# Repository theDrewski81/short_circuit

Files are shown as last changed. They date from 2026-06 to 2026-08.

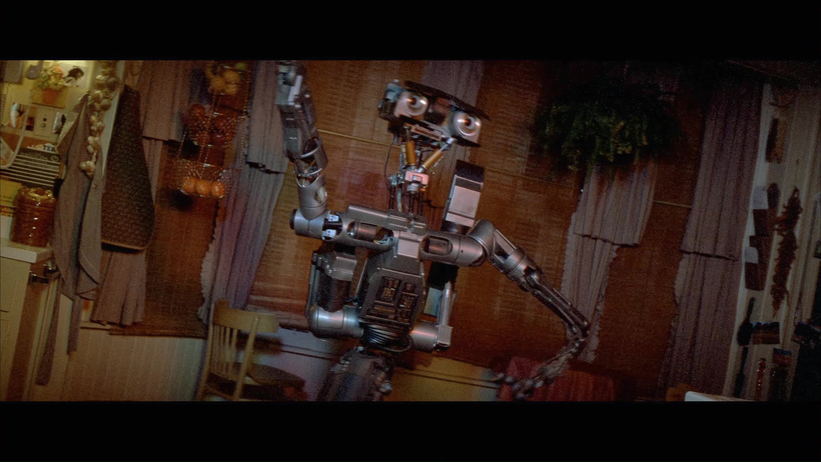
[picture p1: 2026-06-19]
reference_images/f872ac491efb3785fa1dbe327b1345db-o.jpg

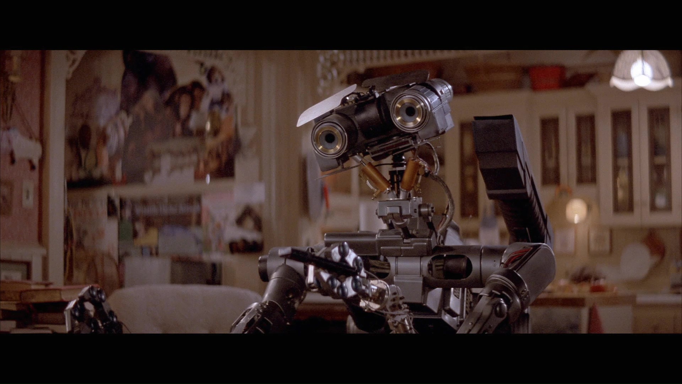
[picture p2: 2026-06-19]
reference_images/b916a9b340c59056be2ff8090a524d04-o.jpg

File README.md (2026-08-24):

# Johnny 5

A playful, Johnny 5-inspired (*Short Circuit*, 1986) autonomous robot. Tread-driven
locomotion, two articulated arms, a rotating head, voice I/O, and visual perception.
An LLM handles reasoning and communication; ML-trained motor policies handle motion
control.

Full project brief: [`CLAUDE.md`](./CLAUDE.md).

## Architecture

Two Raspberry Pi Zero 2 W units with distinct roles, communicating over MQTT via a
Mosquitto broker on the home lab.

- **Pi-M (Motion)** — fixed-rate motor control loop, tread drive, arm/head servos,
  ToF + IMU sensing, LED status ring. Never blocks on the network.
- **Pi-V (Vision)** — camera capture, voice input, and the LLM agent loop. Calls out
  to a home lab LiteLLM proxy and pushes intent updates to Pi-M.

LLM inference runs on existing home lab infrastructure (RTX 3080 / Proxmox cluster)
via LiteLLM — no dedicated serving layer for this project. Motion policies are
trained in MuJoCo on the home lab and deployed to Pi-M as ONNX.

See `src/shared/PROTOCOL.md` for the Pi-M ↔ Pi-V message contract.

## Repository Layout

```
mechanical/   FreeCAD source + STL exports
phases/       Per-phase coordinator documents
src/          motion/ (Pi-M), vision/ (Pi-V), shared/ (message contracts)
simulation/   MuJoCo models and training code
policies/     Trained policy exports (ONNX)
scripts/      Setup, deployment, and maintenance scripts
```

## Status

Current phase, blockers and next steps live in [`PROJECT_STATE.md`](./PROJECT_STATE.md),
which is the project's single source of truth for where the work stands.

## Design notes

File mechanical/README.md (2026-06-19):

# Johnny 5 — Mechanical (FreeCAD, parametric)

All body geometry is generated from a single parameter sheet by headless Python
build scripts. Nothing is modelled by hand in the GUI.

```
mechanical/
  freecad/
    params.csv            single source of truth (locked + design dims)
    j5_params.py          CSV loader + derived geometry (no FreeCAD dependency)
    j5_lib.py             Part-scripting helpers (boxes, bosses, keyed splits, export)
    build_chassis.py      chassis / tread base build  → STL + FCStd
    chassis_assembly_v1.FCStd   (generated)
  stl/                    generated STL exports for printing
  preview/
    validate.py           FreeCAD-free param checks (bed fit, clearance, packaging, mass)
    preview_chassis.py    matplotlib massing preview → PNG
    chassis_massing_v1.png
```

## Generate the chassis

```
cd mechanical/freecad
freecadcmd build_chassis.py          # FreeCAD 1.1.1; writes STLs to ../stl and the FCStd here
```

(or paste `build_chassis.py` into the FreeCAD Python console)

## Check before printing

```
cd mechanical/preview
python3 validate.py                  # all-PASS gate on the parameters
python3 preview_chassis.py           # regenerate the massing preview
```

## Conventions

World origin at the centre of the track footprint, on the ground plane.
**+X right, +Y forward, +Z up.** Edit `params.csv` and re-run — never edit
dimensions inside the scripts. `locked=1` rows trace to the approved BOM and the
Phase 00 handoff; changing one is a phase decision.

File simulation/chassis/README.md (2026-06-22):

# Johnny 5 — Tread Chassis Simulation (Phase 02)

Chassis-only MuJoCo environment for training the locomotion policy. Arms and
head are out of scope here (added in Phase 03); their mass rides on the chassis
as a lumped trunk inertia.

## Files

| File | Role |
|---|---|
| `params.py` | SI-unit parameter bridge. Reads `mechanical/freecad/params.csv` (CAD source of truth) and declares the non-CAD modelling constants (motor torque, friction, mass split, CoM height) with their basis. |
| `build_mjcf.py` | Generates `johnny5_chassis.xml` from `params.py`. Re-run after any params change. |
| `johnny5_chassis.xml` | Generated MJCF. **Do not hand-edit** — change `params.py`/`params.csv` and regenerate. |
| `env.py` | Gymnasium environment `JohnnyChassisEnv` (command-conditioned). |
| `test_env.py` | Pre-training stability + sanity checks (random + scripted rollouts). |
| `TUNING.md` | Sim-vs-reality assumptions to confirm on the bench (Phase 02 Task 6). |

Regenerate the model:

```bash
python3 simulation/chassis/build_mjcf.py
```

## Modelling assumptions

**Treads → four driven wheels.** Each tread is two cylinders (front + rear,
spanning the 120 mm wheelbase) rather than a deformable belt. Deformable track
contact is expensive and numerically fragile, and the policy only needs the
left/right-speed → body-motion mapping. A *single* wheel per side collapses the
fore-aft contact patch to a point, and the tall robot nose-dives; front + rear
wheels restore the support polygon. The real belt couples the front idler to the
rear sprocket, so both turn at track speed — hence all four wheels are driven, in
left/right pairs (the env writes one command to each side's two wheels).

**DC motor → torque actuator + damping droop.** Each wheel is a torque source
(`gear` = stall torque / 2) with joint damping `b = stall / (2·no_load)`. The
factor of two splits one physical motor's torque-speed line across its two
wheels, so the per-side behaviour matches one brushed motor: full command settles
the side near its no-load speed (~0.30 m/s) instead of accelerating without
bound. Stall 0.25 N·m and no-load 12.9 rad/s are datasheet figures scaled from
12 V to the 7.4 V battery-direct rail — **confirm on the bench** (TUNING.md).

**Skid-steer turn resistance is real, not a bug.** Contacts use `condim=3`
(slide friction only). Turning comes from lateral skid of four wheels spread over
the wheelbase, so in-place yaw is resistance-limited. Measured envelope on the
default floor: forward cap ~0.30 m/s, in-place yaw cap ~0.34 rad/s. The env
command ranges (`V_MAX=0.28`, `W_MAX=0.30`) sit just inside these.

**Rear caster → rigid low-friction sphere.** The physical part is a sprung,
swivelling trailing caster; for locomotion it is a rigid low-friction support
sphere placed half the nominal trail behind the rear track edge, giving the same
rearward tip support without joint-tuning fragility.

**Trunk inertia → solid-box proxy.** Mass 1.197 kg at CoM height 0.110 m, with a
box inertia using the tub footprint and an effective height of 0.18 m to account
for the torso/head/arm mass riding above the (collision-only) tub.

## Environment

`JohnnyChassisEnv` — command-conditioned, one policy for all behaviours.

- **Control rate:** 50 Hz (matches the Pi-M motion-loop tick); 10 physics
  substeps per control step at 500 Hz.
- **Action:** `[left, right]` motor effort in `[-1, 1]`, each applied to that
  side's two wheels.
- **Observation (9):** body-frame forward/lateral velocity, yaw rate, roll,
  pitch, left/right encoder velocity, and the command `[v_cmd, w_cmd]`.
- **Command modes:** forward, backward, spin-left, spin-right, arc, stop —
  sampled per episode to cover the four Phase 02 behaviours plus hold.
- **Reward:** `w_vel·exp(-k·(v−v_cmd)²) + w_yaw·exp(-k·(ψ̇−w_cmd)²)
  − energy − stability(roll²+pitch²) − lateral-skid`. Tip-over
  (|roll| or |pitch| > 0.8 rad) terminates with a penalty. Weights are
  constructor kwargs, set from `config.yaml` in training (Task 4).

## Pre-training check

```bash
python3 simulation/chassis/test_env.py
```

Confirms physics stability (no NaN/inf, no spurious tip-overs under random
actions) and that a scripted differential controller out-scores random control —
i.e. the reward is trackable — before committing GPU time to training.

## Training (Task 4)

PPO via Stable-Baselines3, command-conditioned, small MLP (`net_arch: [64, 64]`)
for fast onnxruntime inference on Pi-M. Hyperparameters and reward weights live in
`config.yaml`.

```bash
# full run on the RTX 3080 workstation node (see "Where to run" below)
python3 simulation/chassis/train.py --config config.yaml --n-envs <physical_cores> --device cpu
# -> runs/locomotion_v1/{model.zip, best/, vecnormalize.pkl, tb/}

# export the trained policy for the Pi (raw obs -> action, obs-norm baked in)
python3 simulation/chassis/export_onnx.py --run locomotion_v1
# -> policies/locomotion_v1.onnx
```

`train.py` trains all four Phase 02 behaviours (forward / backward / turn-in-place /
arc) plus stop from a single command-conditioned policy, uses `VecNormalize` for
observation/return normalisation, and saves the normalisation stats so they can be
folded into the ONNX graph at export. Watch progress with
`tensorboard --logdir runs/`.

### Where to run on the home lab

Run the single training job on the **RTX 3080 workstation node** (128 GB RAM),
not the Proxmox cluster. Rationale: throughput here is bound by MuJoCo env
stepping on the CPU, and the policy is a tiny 2x64 MLP whose gradient update is
trivial — a GPU adds little and the CPU<->GPU round-trip can even slow a net this
small. So use `--device cpu` with `--n-envs` set to the box's physical core count
(`SubprocVecEnv` parallelises the rollout across cores); the RTX 3080 is incidental
here, chosen for its cores and RAM, not its CUDA. 3M steps lands in roughly tens of
minutes at ~5k env-steps/s/core.

Bare metal or a single VM/LXC with the cores pinned both work — no GPU passthrough
needed. Reserve the Proxmox cluster for *parallel* hyperparameter sweeps (one run
per VM/LXC via `--run-name`), which is the async-batch case, not a single faster run.

### Sandbox note — why training runs on the home lab, not here

PyTorch/SB3 cannot be installed in the Cowork sandbox: the network proxy blocks
the PyTorch CPU wheel index and stalls the large CUDA wheels. So the SB3 PPO run
is a home-lab step. To still de-risk the pipeline before spending home-lab time,
`cem_smoke.py` is a torch-free check (numpy CEM + onnx/onnxruntime only):

```bash
python3 simulation/chassis/cem_smoke.py
```

It trains a small MLP on the env with the cross-entropy method and confirms (a)
the reward is learnable — trained policy beats random init by a wide margin — and
(b) the ONNX deployment path (raw obs → [-1,1] action, normalisation baked in)
reproduces the numpy forward on onnxruntime with sub-millisecond latency. Outputs
land in `smoke_run/` (a representative 1×16 net, distinct from the production 2×64).
These are throwaway validation artifacts, not the deployed policy.

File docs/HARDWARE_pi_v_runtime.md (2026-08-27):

# Pi-V Runtime Environment – the box, the camera, the dependency file, and the audio gap

What is known about Pi-V, the vision unit, and where each fact comes from. Pairs with
`docs/HARDWARE_pi_m_runtime.md`, which does the same for the motion unit, and with
`docs/HARDWARE_power_harness.md`, which covers Pi-V's wiring rather than its software.

**This document is weaker evidence than its Pi-M counterpart, and the difference matters.**
Every fact in `docs/HARDWARE_pi_m_runtime.md` was learned at the Task 1 bench bringup on
2026-07-12, on the hardware. Nothing here was. Pi-V has had no equivalent bringup session
and no agent session can reach `192.168.1.218`, so every claim below is traced to the
repository file that states it, and everything the repository does not state is marked as
not stated rather than filled in. Where this document and the Pi disagree, the Pi wins and
this document is wrong.

## The box

| | | Source |
|---|---|---|
| Host | `johnny5-vision`, `192.168.1.218` (static) | `phases/PHASE_01_INFRASTRUCTURE.md` task 2; `PROJECT_STATE.md` section 9, 2026-06-20; `scripts/_common.sh` |
| OS | Raspberry Pi OS Lite 64-bit, Trixie | `PROJECT_STATE.md` section 9, 2026-06-20 ("Both Pis on Raspberry Pi OS Lite 64-bit (Trixie)") |
| Login user | `administrator` | same entry; `scripts/_common.sh` default |
| System Python | **Not recorded for Pi-V.** See below. | — |
| venv | `~/johnny5-env` | `phases/PHASE_01_INFRASTRUCTURE.md` task 2 |
| Repo checkout | `~/johnny5` | `phases/PHASE_01_INFRASTRUCTURE.md` task 2; `scripts/_common.sh` `JOHNNY5_REMOTE_PATH` |
| LiteLLM virtual key alias | `johnny5-vision` on the AOS proxy | `PROJECT_STATE.md` section 9, 2026-06-22 |

**The system Python version is an inference, not a record.** `docs/HARDWARE_pi_m_runtime.md`
records Python 3.13 on Pi-M, and `PROJECT_STATE.md` puts both Pis on the same Trixie 64-bit
image, so 3.13 is what should be expected on Pi-V. No repository file states it, and nobody
has checked. Treat it as expected, not known. It is not academic: the Trixie plus Python 3.13
combination is exactly what makes `pip install lgpio` impossible on Pi-M, and any Pi-V package
with the same wheel problem would fail the same way.

**The static IP is NetworkManager-managed and could revert.** It was set with `nmcli` inside
the router's reservation block because dhcpcd is inactive on this OS version, and the profiles
are netplan-managed, so a future `netplan apply` could regenerate them. Recorded at S05 on
2026-06-20 and repeated here because the failure looks like a dead Pi rather than a
configuration change.

## Nothing provisions Pi-V

`scripts/setup_motion_pi.sh` provisions Pi-M: apt packages, I2C, the `pwm-2chan` overlay, the
udev rule, the venv with `--system-site-packages`, `pip install -r`, and a verification block
that prints the resolved path of each GPIO-side import. **There is no `setup_vision_pi.sh`, and
no other script provisions Pi-V.** The gap is real and is not a naming difference.

What does exist for Pi-V is deployment and access, which is a different job:

- `scripts/deploy_vision.sh` rsyncs `src/vision/` and `src/shared/` to the Pi and then runs
  `sudo systemctl restart johnny5-vision`. Its own comment says the service name and management
  are TBD and that the restart assumes a unit that may not exist; the restart is tolerated with
  `|| echo` rather than being fatal. **No systemd unit file for `johnny5-vision` exists in the
  repository.** `scripts/deploy_motion.sh` carries the identical caveat for `johnny5-motion`, so
  the TBD service is symmetric and is not part of the provisioning asymmetry.
- `scripts/ssh_vision.sh` is an SSH wrapper over the same `_common.sh` defaults.
- `scripts/check_health.sh` queries `johnny5/heartbeat/vision` on the broker at
  `MQTT_BROKER_HOST` and reports liveness. It runs from the development machine, not the Pi.

The provisioning steps that were actually performed on Pi-V exist only as prose in
`phases/PHASE_01_INFRASTRUCTURE.md` task 2: `apt install python3-pip python3-venv git
i2c-tools`, `raspi-config` for the camera, `python3 -m venv ~/johnny5-env`, and a clone into
`~/johnny5`. They were run by hand at S05 on 2026-06-20 and have never been captured in a
script, so re-provisioning or replacing Pi-V today means re-reading that task list and
repeating it manually. Whether that gap is worth closing with a `setup_vision_pi.sh` is an open
question raised by this document, not a decision it takes.

## The camera

The camera is the 8 MP 1080p CSI module on the head, one of two owned, connected by ribbon
rather than by GPIO (`BOM.md` section 7 and its Pi-V GPIO map).

Enablement, verbatim from `phases/PHASE_01_INFRASTRUCTURE.md` task 2: enable the camera
interface via `raspi-config`, then confirm the camera is detected with `libcamera-hello`. That
is the whole of the recorded enablement step, and there is no record in the repository of it
having been run or of what it printed.

**Two capture interfaces appear in the repository and they are not the same one.**
`scripts/whats_this_color.py`, the only program here that actually captures a frame, shells out
to `rpicam-still -o <path> --immediate -t 1000 -n`. `phases/PHASE_04_COGNITION.md` task 2
specifies `picamera2` for the real capture pipeline, explicitly rejects the legacy `picamera`
library, and warns that `picamera2` APIs differ between OS versions. That phase document names
Bookworm while this box runs Trixie, so its version caution applies to itself: the
`picamera2` version present on a Trixie image has not been confirmed against what Phase 04
assumes. Neither `picamera2` nor `rpicam-apps` is declared in any requirements file; both are
OS-supplied on Raspberry Pi OS images, and neither presence has been checked here.

## Dependencies are declared in `src/vision/requirements-vision.txt`

That file is the single dependency declaration for Pi-V, created by S18 against O8 and sited
beside the code it serves on the `simulation/chassis/requirements-train.txt` precedent. It
pins `httpx==0.28.1` and `python-dotenv==1.2.3` exactly rather than by range, and its header
explains why: a two-package runtime on a Pi Zero 2 W is not worth a silent minor bump in the
HTTP client.

```
pip install -r src/vision/requirements-vision.txt
```

It covers `src/vision/llm_client.py` plus the two Pi-V bench scripts that drive it,
`scripts/test_llm_client.py` and `scripts/whats_this_color.py`; everything else those three
modules import is standard library. `llm_client.py` imports `httpx` only, and `python-dotenv`
is imported by the two scripts. **The pins are current PyPI releases as of 2026-08-25 and have
not been verified against Pi-V**; the file says so itself, and if a `pip install -r` on the Pi
disagrees with a working install, the Pi wins and the file is corrected to match it.

What the file does not cover is everything Phase 04 adds. The camera library, the VAD model,
the transcription client, the TTS path, the MQTT client and the WS2812B driver for the mouth
array are all named in `phases/PHASE_04_COGNITION.md` and declared nowhere. That is expected
for unwritten code and is noted so the file is not mistaken for a complete Pi-V runtime.

## Configuration comes from `.env`

`.env` is gitignored on both Pis; `.env.example` at the repository root is the committed
template and carries the confirmed values and their rationale. The Pi-V half of it is the
LiteLLM client block and the shared MQTT block.

`LITELLM_ENDPOINT` is the existing Agentic OS proxy at `http://192.168.1.223:4000/v1`, reused
rather than rebuilt. `LITELLM_MODEL` is `vision-batch`, which routes to `llava:7b` on the
CPU-only Ollama node ms3 at `192.168.1.225`, chosen so vision inference does not contend with
desktop GPU work. `LITELLM_TIMEOUT` is **60.0**, not the 8.0 that `LiteLLMConfig` defaults to
in code: llava on a CPU node takes 15 to 40 seconds per image and longer on a cold load, and
the 8.0 s placeholder from the Phase 01 task list would have abandoned every call before the
model answered. `LiteLLMConfig.from_env()` raises on a missing endpoint, key or model rather
than falling back to a default, on the reasoning that a wrong endpoint is worse than a loud
failure.

The MQTT block points at the Mosquitto LXC `sn-mosquitto` at `192.168.1.227:1883`, confirmed
live 2026-06-20.

## Audio does not work yet, and the overlay that would fix it is unwritten

All audio is on Pi-V: the INMP441 I²S MEMS microphone and the MAX98357A I²S class-D amplifier
share one I²S bus, consolidated here at S01 on 2026-06-17 specifically to free Pi-M's I²S. On
the Pi-V header that is BCLK on GPIO18, LRCLK on GPIO19, mic data in on GPIO20 and amplifier
data out on GPIO21 (`BOM.md` Pi-V GPIO map, and the `SIG_I2S_*` nets in
`docs/HARDWARE_power_harness.md`).

**Two codecs on one bus need a device-tree overlay that has never been written.** The stock
`max98357a` and `googlevoicehat` overlays conflict; what is required is a custom combined
`simple-audio-card` overlay with one CPU DAI and two codec DAIs. This is **O1** in
`PROJECT_STATE.md` section 7, open since 2026-06-17, owned by a worker session and due in
Phase 04. It is referenced in `BOM.md`, in `phases/PHASE_00_HARDWARE.md`, and on the power
harness schematic, and until now it has been recorded only in prose with no home.

**This file is that home.** When the overlay is written, it belongs in this document, in the
form Pi-M's `pwm-2chan` section takes: the exact `/boot/firmware/config.txt` line, why each
argument is load-bearing, what the failure looks like without it, and the one command that
proves it loaded after a reboot. **It is deliberately not attempted here.** Writing a
device-tree overlay for two codecs that no session can test on the hardware they run on would
be a gate met against an unbuilt artifact, which this project has already done once and
recorded the lesson for. It stays Phase 04 work, to be done with the mic and amplifier wired
and a Pi in front of whoever is doing it. Half-duplex turn-taking with the mic gated during
playback is the intended behaviour, also Phase 04; there is no acoustic echo cancellation in
V1.

## Hardware PWM on Pi-V is unrecorded

`BOM.md` assigns the 1 W navigation light to Pi-V GPIO13 as a hardware PWM output driving a
MOSFET gate, and `docs/HARDWARE_power_harness.md` carries the same on `SIG_NAV_PWM`. Pi-M
needed an explicit `dtoverlay=pwm-2chan,pin=12,func=4,pin2=13,func2=4` line and a reboot before
`/sys/class/pwm` was populated at all. **No equivalent line is recorded anywhere for Pi-V**,
and whether one is needed there, and whether it can coexist with the I²S assignment on the same
header, is not answered by any file in this repository. Flagged rather than guessed; it belongs
with the O1 audio work, since both are `config.txt` questions on the same box.

## The Pi-V header, for reference

From `BOM.md`'s Pi-V GPIO pin map. 40-pin header, 3.3 V logic.

| Function | GPIO (BCM) | Notes |
|---|---|---|
| CSI camera | (ribbon) | Not GPIO |
| I²S BCLK / LRCLK | 18 / 19 | PCM clock / frame-sync, shared by mic and amplifier |
| I²S DIN (mic SD) | 20 | INMP441 into the Pi |
| I²S DOUT (amp DIN) | 21 | Pi into the MAX98357A |
| WS2812B mouth array | 10 | SPI0 MOSI, via a 74AHCT125 level shifter |
| Navigation light | 13 | Hardware PWM to a MOSFET gate |

Inter-Pi messaging runs over the WiFi LAN via the broker; no GPIO cross-link is reserved.

## What in this document is unverified

Stated once, in one place, so it cannot be missed:

- **Everything about the running state of Pi-V.** No agent session can reach `192.168.1.218`,
  and Pi-V has had no bench bringup session of the kind that produced the Pi-M document. The
  host, OS, user, venv path and checkout path are all as configured at S05 on 2026-06-20 and
  as the deployment scripts assume, not as observed since.
- **The system Python version**, which no file records for Pi-V.
- **The camera enablement step**, which is a documented instruction with no record of its
  having been run or of `libcamera-hello` succeeding.
- **The dependency pins**, which are PyPI releases as of 2026-08-25 and have never met the Pi.
- **The presence of `picamera2` or `rpicam-apps`**, and their versions on a Trixie image.

The way to close all of these at once is a Pi-V bringup session with the box in hand, the way
2026-07-12 closed them for Pi-M. Until then this document records what the repository knows,
which is not the same as what is true.

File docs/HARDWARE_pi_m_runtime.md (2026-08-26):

# Pi-M Runtime Environment — venv, GPIO packages, hardware PWM

What `scripts/setup_motion_pi.sh` provisions on Pi-M and, more usefully, the three
things about that box which are not obvious from reading the script. Pairs with
`docs/HARDWARE_drive_bringup.md`, which covers the wiring rather than the software.

Every fact here was learned at the Task 1 bench bringup on 2026-07-12 and lived
until 2026-08-25 only in a loose project-memory note at the repository root, which
is why `setup_motion_pi.sh` went on carrying an install line the bench had already
proved could not work. **None of it has been re-verified since 2026-07-12**, and no
agent session can reach Pi-M to try. Where this document and the Pi disagree, the Pi
wins and this document is wrong.

## The box

| | |
|---|---|
| Host | `johnny5-motion`, `192.168.1.217` (static) |
| OS | Raspberry Pi OS Lite 64-bit, Trixie, aarch64 |
| Login user | `administrator` |
| System Python | 3.13 |
| venv | `~/johnny5-env` |

## The venv is `~/johnny5-env`

Not `~/johnny5/venv`. `setup_motion_pi.sh` defaulted `JOHNNY5_VENV` to the latter
until 2026-08-25, so re-running it built a second venv beside the working one
instead of updating it. The default now matches the Pi. `JOHNNY5_VENV` still
overrides it for anyone provisioning a different box.

```
source ~/johnny5-env/bin/activate
```

## gpiozero and lgpio come from apt, not pip

`pip install lgpio` cannot succeed on this platform. Trixie ships Python 3.13, there
is no cp313 wheel on the piwheels mirror, and the sdist falls back to compiling
against a system `-llgpio` that a stock image does not have. Installing `swig` does
not change the outcome; the missing piece is the library, not the binding generator.

The route that works, and what `setup_motion_pi.sh` now does:

```
sudo apt-get install -y python3-gpiozero python3-lgpio
```

then create the venv with `--system-site-packages`, or set
`include-system-site-packages = true` in `~/johnny5-env/pyvenv.cfg` if it already
exists, so the venv can see them. The script does both, repairing an existing
`pyvenv.cfg` in place — Pi-M's own venv predates the fix and needs the repair rather
than the flag.

Everything else in the motion stack is still pip, from
`src/motion/requirements-motion.txt`: `onnxruntime`, `numpy`, `smbus2`,
`rpi-hardware-pwm`, `paho-mqtt`. That file is the single list; the script reads it.

`import gpiozero` resolving to a path under `/usr/lib/python3/dist-packages` is the
check that the system-site-packages link is live. The script prints the resolved
path of each of the three GPIO-side modules at the end of its run for exactly that
reason.

## Hardware PWM needs the overlay and a reboot

`/sys/class/pwm` is empty — not wrong, empty — until this line is in
`/boot/firmware/config.txt` and the Pi has been rebooted:

```
dtoverlay=pwm-2chan,pin=12,func=4,pin2=13,func2=4
```

The `pin=`/`pin2=` arguments are load-bearing. The stock `pwm-2chan` overlay puts
PWM0 and PWM1 on GPIO18 and GPIO19; the BOM puts motor PWMA and PWMB on GPIO12 and
GPIO13, and `func=4` selects ALT0 on those pins. Without the arguments the peripheral
comes up on pins nothing is wired to, and the failure looks like dead motors rather
than like a configuration error.

After the reboot, `ls /sys/class/pwm` shows `pwmchip0` with `npwm=2`.
`src/motion/motor_driver.py` drives chip 0.

## The udev rule was not needed on this box

`setup_motion_pi.sh` installs `/etc/udev/rules.d/99-pwm.rules` and adds the login
user to `gpio` so that PWM sysfs is writable without sudo. On Pi-M as built this was
never exercised: GPIO access through gpiozero and lgpio worked with no extra
permissions and no PWM sysfs permission error was hit at the 2026-07-12 bringup. The
rule is kept because a fresh or differently configured image may still need it, but
if it ever misbehaves, it is removable on this hardware without breaking the bench
test.

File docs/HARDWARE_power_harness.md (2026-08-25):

# Power Wiring and Harness — Johnny 5

Companion document to `docs/diagrams/power_harness_schematic.svg`. Together they are the
formal power and harness definition for the whole robot, from the XT60 pack lead to every
load, and they close blocker B5. Nothing in the power architecture should be ordered
against anything else.

The drawing is the picture; this file is the data. Where a figure appears in both, this
file is the one `scripts/check_harness_nets.py` parses, and the guard asserts that the two
carry the same set of net names.

---

## 1. Architecture

One 2S LiPo feeds one fused, switched trunk into a distribution board that carries the star
ground and three rails. The motor rail is battery-direct, roughly 7.4 V nominal and 8.4 V at
full charge, and goes only to the TB6612FNG VM pin, so motor transients never reach anything
else. A 5 V synchronous buck carries both Pi Zero 2 W units, both WS2812B strings with their
level shifters, the MAX98357A amplifier and the navigation light. A 6 V synchronous buck
carries the Waveshare Bus Servo Adapter and through it all six SCS0009 servos; the servos are
regulated rather than battery-direct because 8.4 V exceeds the SCS0009 7.4 V maximum and would
damage them on a freshly charged pack.

Two derived 3.3 V supplies come from the Pi header pins rather than from a converter. Pi-M's
3.3 V pin carries the I²C sensors, both motor encoders and the TB6612 logic supply, which is
what keeps every logic and encoder output GPIO-safe. Pi-V's 3.3 V pin carries the INMP441
microphone.

The fuse sits between the pack and the master switch, so the switch itself is protected. The
switch is the only thing between a charged pack and a live harness, and everything downstream
of it, telemetry included, is dead when it is open.

## 2. Reading the drawing

Power conductors are drawn thick and solid and coloured by rail: orange for battery-direct
VBAT, red for 5 V, purple for 6 V, pink for the two derived 3.3 V supplies, black for ground.
Signal conductors are drawn thin and dashed in slate. A filled dot is a junction; two
conductors crossing without a dot are not connected.

Ground is drawn as a bus in the lower band and as ground symbols in the upper band. Both mean
the same thing: every return lands on one star point on the distribution board. The symbols
are used where a routed line would have to cross most of the drawing to say the same thing.

## 3. Net table

Net names carry their rail as a prefix. `VBAT_`, `5V_`, `6V_`, `3V3M_` and `3V3V_` are rails;
`SIG_`, `OUT_` and `GND_` are not. Every rail-prefixed net declares either `[peak N A]`, the
worst-case current that net carries, or `[reflected]`, meaning it is an inter-rail feed whose
current is accounted for on the rail it supplies rather than on the rail it draws from. The
guard rejects a rail-prefixed net that declares neither, so a forgotten figure fails loudly
instead of summing to zero.

Passive components are properties of the net they sit in rather than endpoints of their own.
A series resistor or a bulk capacitor does not terminate a conductor, and modelling them as
endpoints would have forced an exemption into the endpoint check. Their values are called out
in the Notes column and every value is a line item in `BOM.md` section 6.

Where a net reaches more than one device, the endpoints are separated by a plus sign, so that a
comma inside a single endpoint stays unambiguous to a reader and to the guard.

Conductor lengths are not specified. The harness is cut to fit at assembly; the build order in
section 7 says when.

| Net | Source | Destination | Gauge | Connector | Notes |
|---|---|---|---|---|---|
| VBAT_PACK | Battery XT60 (+) | Fuse holder, line side | 18 AWG silicone | XT60 pair | [reflected] The only conductor upstream of the fuse. Keep it as short as the battery bay allows. |
| VBAT_FUSED | Fuse holder, load side | Master switch, terminal 1 | 18 AWG silicone | 6.35 mm insulated spade | [reflected] 7.5 A inline blade fuse. Fuse before switch, so a switch fault is also protected. |
| VBAT_SW | Master switch, terminal 2 | Distribution board VBAT pad | 18 AWG silicone | 6.35 mm insulated spade | [reflected] Everything downstream is dead with the switch open. |
| VBAT_VM | Distribution board VBAT pad | TB6612 VM | 18 AWG silicone | soldered to breakout pad | [peak 2.00 A] 1000 µF electrolytic plus 0.1 µF ceramic across VM to GND at the breakout. Electrolytic polarity is critical. |
| VBAT_BUCK5_IN | Distribution board VBAT pad | Buck converter (5 V) IN+ | 18 AWG silicone | screw terminal | [reflected] Set the output to 5.0 V on the bench before any load is connected. |
| VBAT_BUCK6_IN | Distribution board VBAT pad | Buck converter (6 V) IN+ | 18 AWG silicone | screw terminal | [reflected] Set the output to 6.0 V on the bench before any servo is connected. |
| VBAT_SENSE | Distribution board VBAT pad | ADS1115 sense divider, 100 kΩ upper leg | 26 AWG | soldered on the distribution board | [peak 0.00 A] 57 uA at 8.4 V. Downstream of the switch, so telemetry reads zero when the robot is off, which is intended. |
| 5V_PI_M | Buck converter (5 V) OUT+ | Pi-M 5 V (pin 2) | 20 AWG silicone | 2-pin JST-XH 2.54 | [peak 0.40 A] 1000 µF electrolytic across the 5 V rail at the distribution board. |
| 5V_PI_V | Buck converter (5 V) OUT+ | Pi-V 5 V (pin 2) | 20 AWG silicone | 2-pin JST-XH 2.54 | [peak 0.40 A] Runs up through the torso. Keep it clear of the servo bus cable. |
| 5V_LED_M | Distribution board 5 V pad | WS2812B eye pixels and battery gauge + 74AHCT125 (Pi-M) VCC | 22 AWG | 3-pin JST-XH 2.54 (5 V, DIN, GND) | [peak 0.23 A] Seven pixels, two eyes plus a five-pixel gauge. 0.1 µF ceramic at the shifter VCC. |
| 5V_LED_V | Distribution board 5 V pad | WS2812B mouth array + 74AHCT125 (Pi-V) VCC | 22 AWG | 3-pin JST-XH 2.54 (5 V, DIN, GND) | [peak 0.27 A] Eight pixels. 0.1 µF ceramic at the shifter VCC. |
| 5V_AMP | Distribution board 5 V pad | MAX98357A VIN | 22 AWG | 2-pin JST-XH 2.54 | [peak 1.00 A] Largest transient on the rail. 0.1 µF ceramic at the amplifier. |
| 5V_NAVLIGHT | Distribution board 5 V pad | Navigation light LED module, anode | 22 AWG | 2-pin JST-XH 2.54 | [peak 0.30 A] Switched on the low side. The module carries its own current-setting resistor. |
| 6V_SERVO_BUS | Buck converter (6 V) OUT+ | Waveshare Bus Servo Adapter V+ | 18 AWG silicone | screw terminal | [peak 3.00 A] 1000 µF electrolytic at the adapter input. Never battery-direct: 8.4 V exceeds the SCS0009 7.4 V maximum. |
| 3V3M_SENSORS | Pi-M 3.3 V (pin 1) | VL53L1X VIN + MPU-6050 VCC + ADS1115 VDD | 26 AWG | 4-pin JST-XH 2.54 per device | [peak 0.05 A] Three devices on one supply and one I²C bus. |
| 3V3M_ENC | Pi-M 3.3 V (pin 17) | Drive gearmotor left encoder Vcc + Drive gearmotor right encoder Vcc | 28 AWG in the supplied motor cable | 6-pin JST SH 1.0 mm | [peak 0.02 A] 3.3 V so both encoder outputs are GPIO-safe. |
| 3V3M_TB_VCC | Pi-M 3.3 V (pin 17) | TB6612 VCC | 26 AWG | soldered to breakout pad | [peak 0.01 A] Logic supply only. 5 V here would damage Pi-M GPIO, and the TB6612 reverse protection covers VM, not VCC. |
| 3V3V_MIC | Pi-V 3.3 V (pin 1) | INMP441 VDD | 26 AWG | 5-pin JST-XH 2.54 | [peak 0.01 A] L/R strapped to GND for the left channel. |
| GND_BATT | Battery XT60 (-) | Distribution board star ground | 18 AWG silicone | XT60 pair | The star point is the only place returns meet. |
| GND_MOTOR | TB6612 GND | Distribution board star ground | 18 AWG silicone | soldered to breakout pad | Own conductor, so motor return never shares a path with logic return. |
| GND_SERVO | Waveshare Bus Servo Adapter GND | Distribution board star ground | 18 AWG silicone | screw terminal | Own conductor, for the same reason. |
| GND_BUCK5 | Buck converter (5 V) IN- and OUT- | Distribution board star ground | 18 AWG silicone | screw terminal | Input and output returns are common inside the module. |
| GND_BUCK6 | Buck converter (6 V) IN- and OUT- | Distribution board star ground | 18 AWG silicone | screw terminal | Input and output returns are common inside the module. |
| GND_PI_M | Pi-M GND (pin 6) | Distribution board star ground | 20 AWG | in the 5V_PI_M connector shell | Pi-M power return. |
| GND_PI_V | Pi-V GND (pin 6) | Distribution board star ground | 20 AWG | in the 5V_PI_V connector shell | Pi-V power return. |
| GND_SIG_M | Pi-M GND (pin 9) | TB6612 GND + VL53L1X GND + MPU-6050 GND + ADS1115 GND | 26 AWG | in each device connector shell | Signal return local to Pi-M. Reaches the star through GND_PI_M. |
| GND_ENC | Drive gearmotor left encoder GND + Drive gearmotor right encoder GND | Pi-M GND (pin 14) | 28 AWG in the supplied motor cable | 6-pin JST SH 1.0 mm | Encoder return follows its signal pair back to the Pi, not to the motor return. |
| GND_LED_M | WS2812B eye pixels and battery gauge + 74AHCT125 (Pi-M) GND | Distribution board star ground | 22 AWG | in the 5V_LED_M connector shell | |
| GND_LED_V | WS2812B mouth array + 74AHCT125 (Pi-V) GND | Distribution board star ground | 22 AWG | in the 5V_LED_V connector shell | |
| GND_AMP | MAX98357A GND | Distribution board star ground | 22 AWG | in the 5V_AMP connector shell | |
| GND_NAV | MOSFET source | Distribution board star ground | 22 AWG | 2-pin JST-XH 2.54 | Low-side switch return. |
| GND_MIC | INMP441 GND | Pi-V GND (pin 9) | 26 AWG | in the INMP441 connector shell | |
| OUT_MOT_L | TB6612 AO1, AO2 | Drive gearmotor left, M1 and M2 | 22 AWG to the connector, 28 AWG in the supplied motor cable | 6-pin JST SH 1.0 mm | Bench-verified crossover: RED to AO2, BLK to AO1. Recorded 2026-07-12 in `simulation/chassis/TUNING.md`. Do not undo it in software; `MotorDriver` stays at `invert_*=False`. |
| OUT_MOT_R | TB6612 BO1, BO2 | Drive gearmotor right, M1 and M2 | 22 AWG to the connector, 28 AWG in the supplied motor cable | 6-pin JST SH 1.0 mm | RED to BO1, BLK to BO2, uncrossed. |
| OUT_SERVO_BUS | Waveshare Bus Servo Adapter servo port | SCS0009 servo chain, six units daisy-chained | 22 AWG in the supplied 3-wire lead | Feetech 3-pin 1.25 mm | 6 V, GND and half-duplex data in one chain. IDs 1 to 6: left shoulder, right shoulder, head yaw, head nod, utility-box tilt, brow roll. |
| OUT_SPK | MAX98357A OUT+ and OUT- | Speaker | 22 AWG | 2-pin JST-PH 2.0 | Bridge-tied output. Neither leg is ground. Tying the minus leg to the star will damage the amplifier. |
| OUT_NAV_LED | Navigation light LED module, cathode | MOSFET drain | 22 AWG | 2-pin JST-XH 2.54 | Switched on the low side so the gate stays referenced to Pi-V ground. |
| OUT_SENSE_TAP | ADS1115 sense divider midpoint, 100 kΩ over 47 kΩ | ADS1115 A0 | 26 AWG | soldered on the distribution board | 8.4 V divides to 2.685 V, inside both the 3.3 V VDD and the 4.096 V full-scale range. 0.1 µF ceramic across the 47 kΩ leg. |
| OUT_LED_M_DATA | 74AHCT125 (Pi-M) Y1 | WS2812B eye pixels and battery gauge, DIN | 24 AWG | in the 5V_LED_M connector shell | 330 Ω in series at the shifter output. |
| OUT_LED_V_DATA | 74AHCT125 (Pi-V) Y1 | WS2812B mouth array, DIN | 24 AWG | in the 5V_LED_V connector shell | 330 Ω in series at the shifter output. |
| SIG_PWMA | Pi-M GPIO12 (pin 32) | TB6612 PWMA | 26 AWG | 2.54 mm IDC or Dupont | Hardware PWM0, about 20 kHz. |
| SIG_AIN1 | Pi-M GPIO5 (pin 29) | TB6612 AIN1 | 26 AWG | 2.54 mm IDC or Dupont | Left channel direction. |
| SIG_AIN2 | Pi-M GPIO6 (pin 31) | TB6612 AIN2 | 26 AWG | 2.54 mm IDC or Dupont | Left channel direction. |
| SIG_PWMB | Pi-M GPIO13 (pin 33) | TB6612 PWMB | 26 AWG | 2.54 mm IDC or Dupont | Hardware PWM1, about 20 kHz. |
| SIG_BIN1 | Pi-M GPIO16 (pin 36) | TB6612 BIN1 | 26 AWG | 2.54 mm IDC or Dupont | Right channel direction. |
| SIG_BIN2 | Pi-M GPIO26 (pin 37) | TB6612 BIN2 | 26 AWG | 2.54 mm IDC or Dupont | Right channel direction. |
| SIG_STBY | Pi-M GPIO20 (pin 38) | TB6612 STBY | 26 AWG | 2.54 mm IDC or Dupont | 100 kΩ pull-down to the star fitted at the TB6612 end. Motors are off on boot, after a crash and whenever the GPIO floats. This is the primary fail-safe. |
| SIG_ENC_L_A | Drive gearmotor left encoder A, yellow | Pi-M GPIO17 (pin 11) | 28 AWG in the supplied motor cable | 6-pin JST SH 1.0 mm | |
| SIG_ENC_L_B | Drive gearmotor left encoder B, white | Pi-M GPIO27 (pin 13) | 28 AWG in the supplied motor cable | 6-pin JST SH 1.0 mm | |
| SIG_ENC_R_A | Drive gearmotor right encoder A, yellow | Pi-M GPIO23 (pin 16) | 28 AWG in the supplied motor cable | 6-pin JST SH 1.0 mm | Bench-verified crossover: A and B are swapped on this motor only, recorded 2026-07-12 in `simulation/chassis/TUNING.md`. The `BOM.md` pin map entry "Encoder M2 A/B = 22/23" names the Pi-side channel pair, not the wire colours. |
| SIG_ENC_R_B | Drive gearmotor right encoder B, white | Pi-M GPIO22 (pin 15) | 28 AWG in the supplied motor cable | 6-pin JST SH 1.0 mm | Second half of the crossover above. |
| SIG_I2C_SDA | Pi-M GPIO2 (pin 3) | VL53L1X SDA + MPU-6050 SDA + ADS1115 SDA | 26 AWG | 4-pin JST-XH 2.54 per device | One bus, three addresses: 0x29, 0x68, 0x48. |
| SIG_I2C_SCL | Pi-M GPIO3 (pin 5) | VL53L1X SCL + MPU-6050 SCL + ADS1115 SCL | 26 AWG | 4-pin JST-XH 2.54 per device | Bus pull-ups are on the carrier boards. |
| SIG_TOF_XSHUT | Pi-M GPIO24 (pin 18) | VL53L1X XSHUT | 26 AWG | in the VL53L1X connector shell | Reset control. Held low keeps the sensor off the bus. |
| SIG_TOF_INT | Pi-M GPIO25 (pin 22) | VL53L1X INT | 26 AWG | in the VL53L1X connector shell | Optional data-ready interrupt. Fit the wire even if unused. |
| SIG_SERVO_TX | Pi-M GPIO14 (pin 8) | Waveshare Bus Servo Adapter RXD | 26 AWG | 2.54 mm IDC or Dupont | PL011 on /dev/serial0. `dtoverlay=disable-bt` must be present in /boot/firmware/config.txt or this lands on the mini-UART and drifts with CPU frequency. |
| SIG_SERVO_RX | Pi-M GPIO15 (pin 10) | Waveshare Bus Servo Adapter TXD | 26 AWG | 2.54 mm IDC or Dupont | Half-duplex bus; the adapter handles direction. |
| SIG_LED_M_DATA3V3 | Pi-M GPIO10 (pin 19) | 74AHCT125 (Pi-M) A1 | 26 AWG | 2.54 mm IDC or Dupont | SPI0 MOSI. Shifter OE1 to GND; unused inputs to GND and unused OE pins to VCC. |
| SIG_I2S_BCLK | Pi-V GPIO18 (pin 12) | INMP441 SCK + MAX98357A BCLK | 26 AWG | in each device connector shell | Shared bit clock, one CPU DAI and two codec DAIs. |
| SIG_I2S_LRCLK | Pi-V GPIO19 (pin 35) | INMP441 WS + MAX98357A LRC | 26 AWG | in each device connector shell | Shared frame sync. |
| SIG_I2S_DIN | Pi-V GPIO20 (pin 38) | INMP441 SD | 26 AWG | in the INMP441 connector shell | Microphone into the Pi. |
| SIG_I2S_DOUT | Pi-V GPIO21 (pin 40) | MAX98357A DIN | 26 AWG | in the MAX98357A connector shell | Pi into the amplifier. |
| SIG_LED_V_DATA3V3 | Pi-V GPIO10 (pin 19) | 74AHCT125 (Pi-V) A1 | 26 AWG | 2.54 mm IDC or Dupont | SPI0 MOSI. Same shifter tie-off as the Pi-M side. |
| SIG_NAV_PWM | Pi-V GPIO13 (pin 33) | MOSFET gate | 26 AWG | 3-pin JST-XH 2.54 | Hardware PWM to a logic-level gate. The module carries its own gate pull-down. |

---

## 4. Per-rail current summary, reconciled against BOM.md

Peak column is the sum of the `[peak N A]` tags on that rail's nets. Budget column is the sum
of the matching rows in the `BOM.md` Power Budget. Rating is the converter or protection
rating stated in `BOM.md` section 6.

| Rail | Nets summed | Peak from net table | BOM Power Budget | Rating | Source of the rating |
|---|---|---|---|---|---|
| VBAT (battery-direct, 7.4 V nom) | 2 | 2.00 A | 2.0 A | 7.5 A | Inline blade fuse, section 6 |
| 5 V | 6 | 2.60 A | 2.6 A | 5 A | Buck converter, section 6 |
| 6 V | 1 | 3.00 A | 3.0 A | 5 A | Buck converter, section 6 |
| 3.3 V (Pi-derived, both Pis) | 4 | 0.09 A | 0.05 A | 0.25 A | Not in BOM. Declared in the guard as a conservative limit for a Pi Zero 2 W 3.3 V header pin. |

Two reconciliation rules make those columns comparable, and the guard applies both.

The Power Budget lists sensors on a rail cell reading "3.3 V / 5 V". That row is assigned to
the first rail named, 3.3 V, so the 0.05 A is not counted twice. Without this rule the 5 V
budget reads 2.65 A against a net table that legitimately totals 2.60 A.

The net table is finer-grained than the Power Budget, so a rail's net-table peak is allowed to
exceed its budget but not to fall below it, and the excess is capped at 0.25 A. The only rail
where this bites is 3.3 V, where the net table pays for the encoder supplies and the TB6612
logic supply that the Power Budget rolls into other rows. A missing load makes the net table
fall below the budget and fails; an invented one blows the cap and fails.

## 5. Battery-side worst case and fuse margin

Reflected current is computed at 7.4 V nominal with 90 % converter efficiency, which is a
stated assumption rather than a measured figure.

| Path | Calculation | Current |
|---|---|---|
| Motor rail, direct | 2.00 A | 2.00 A |
| 5 V buck input | 2.60 A x 5.0 V / (7.4 V x 0.90) | 1.95 A |
| 6 V buck input | 3.00 A x 6.0 V / (7.4 V x 0.90) | 2.70 A |
| **Total at the fuse** | | **6.65 A** |

That leaves 0.85 A, about 11 %, under the 7.5 A fuse. It is a synthetic number: every load
peaking at once is not an operating point the robot reaches, because a servo stall and a motor
stall and speech at full volume do not coincide. It is still the tightest margin in the power
architecture and it is worth knowing before the fuse is bought. Two things could make it real
rather than synthetic. A blade fuse is slow enough to ride out the inrush of three bulk
capacitors charging at switch-on, but a fast-blow fuse in the same holder would not be, so
specify the blade type and not a glass fast-blow. And if the deferred motor-rail boost to
9–10 V is ever taken up, this calculation must be redone before it is wired.

## 6. Worked trace: battery positive to the amplifier

Every component, gauge and connector between the pack and one load, without opening another
file. The load chosen is the MAX98357A, because it is the furthest thing from the battery and
crosses two rails on the way.

Battery XT60 positive terminal, out on 18 AWG silicone through the XT60 pair, into the line
side of the inline fuse holder carrying a 7.5 A blade fuse. Out of the fuse holder on 18 AWG
silicone to a 6.35 mm insulated spade on terminal 1 of the SPST master switch. Out of terminal
2 on 18 AWG silicone, again on a 6.35 mm spade, to the VBAT pad of the distribution board,
which is also where the star ground sits. From the VBAT pad on 18 AWG silicone into the screw
terminal of the 5 V buck converter input, which draws 1.95 A at worst case. Out of the buck
converter output at 5.0 V into the distribution board 5 V pad, where a 1000 µF electrolytic
sits across the rail. From the 5 V pad on 22 AWG through a 2-pin JST-XH 2.54 connector to the
MAX98357A VIN pin, with a 0.1 µF ceramic at the amplifier, carrying 1.00 A at peak.

The return is the mirror image: MAX98357A GND, 22 AWG in the same connector shell, to the star
ground point on the distribution board, and out to the battery XT60 negative terminal on
18 AWG silicone. The speaker is not part of that return. The MAX98357A output is bridge-tied
and neither of its two legs is ground.

## 7. Harness build order

Build it in this order and nothing is ever live when it should not be.

Start with the pack out of the robot and the master switch open, and leave it that way until
step 8. Build the distribution board first: the star ground point, the VBAT pad, the 5 V pad,
the three 1000 µF electrolytics, the sense divider and its 0.1 µF, and the 100 kΩ STBY
pull-down if it is boarded rather than fitted at the TB6612. Nothing is connected to it yet.

Second, build the trunk as a subassembly on the bench, XT60 through fuse holder through master
switch to the distribution board VBAT pad, and confirm with a meter that the switch open reads
open circuit and the switch closed reads short, before the pack has ever been near it.

Third, set both buck converters on a bench supply at 7.4 V with no load. Set one to 5.00 V and
one to 6.00 V, mark them, and only then wire their inputs to the VBAT pad and their returns to
the star. Setting a buck under load is how a servo bus sees 8 V.

Fourth, wire ground before power for every remaining block. Every return listed in the net
table lands on the star, and the returns that do not, GND_SIG_M, GND_ENC and GND_MIC, land on
their Pi and reach the star through that Pi's power return.

Fifth, wire the 5 V rail loads, then the 3.3 V loads from the Pi header pins, then the signal
harness. The TB6612 logic supply is 3.3 V and the amplifier supply is 5 V; confirm each with a
meter at the connector before the connector is mated, because the TB6612 reverse protection
covers VM only.

Sixth, wire the motor rail last on the power side: VBAT pad to TB6612 VM, with the 1000 µF and
the 0.1 µF fitted before the motor leads. Fit the STBY pull-down and confirm with a meter that
STBY reads low with the Pi off.

Seventh, wire the 6 V rail to the servo adapter and the servo chain, having already confirmed
6.00 V at the buck output in step three.

Eighth and last, connect the pack. First power-up is staged: switch on with both Pis powered
and the motor rail fused but the TB6612 VM lead left off, confirm 5.00 V and 6.00 V and a sane
ADS1115 reading, then power down, fit the VM lead and repeat. Keep fingers clear of the
sprockets and treads from this point on.

## 8. What this document does not settle

Conductor lengths, because the harness is cut to fit. The physical routing of the trunk through
the tub, which waits on the electronics shelf being printed and the pack strapped in. The
6-pin JST SH motor cables, which Pololu sells separately from the motors and which are not yet
a `BOM.md` line item. And whether the 11 % fuse margin in section 5 should be spent on a
larger fuse, which is a decision for whoever owns the ordering rather than for this drawing.

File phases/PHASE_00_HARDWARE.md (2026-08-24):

# Phase 00 — Hardware Design & BOM

> **Status lives in [`PROJECT_STATE.md`](../PROJECT_STATE.md), not here.** This document
> defines what the work *is* — objective, gate condition, tasks, known constraints, and the
> engineering record of the sessions that worked on it. For where the project stands, what is
> blocked, and what happens next, read `PROJECT_STATE.md`. Any status claim left in this file
> is historical context, not authority.

## Objective

Finalize all hardware selections and produce a complete, orderable Bill of Materials. Baseline the Johnny 5 body design in FreeCAD. No software is written in this phase, but all physical constraints that affect software design are locked in. Ordering should not happen and printing should not start until the gate is met.

---

## Gate Condition

**BOM is finalized and approved. Body design is baselined in FreeCAD 1.1.1.**

Finalized means: every component is selected to a specific part number with a known supplier. Approved means: Andrew has explicitly confirmed the BOM before ordering.

---

## Context

Andrew already owns: two Raspberry Pi Zero 2 W units (with microSD cards, pre-soldered GPIO headers, and 8MP 1080p CSI cameras), a Creality Ender 3 Pro, and FreeCAD 1.1.1.

The GrowBot reference (britcruise9/GrowBot) uses Feetech SCS0009 serial bus servos, a single-cell LiPo with MT3608 boost to 5V, and breadboard-level power distribution. Johnny 5 has a substantially larger actuator set (2 DC motors for treads + 3 serial bus servos for arms and head) and a more complex body design. The power architecture must be designed for this load, not copied directly from GrowBot.

Key constraint: the Pi Zero 2 W GPIO header is 40-pin, 3.3V logic. Motor drivers must be logic-level compatible or use a level shifter.

---

## Tasks

### 1. Tread Drive System

Select DC motors and H-bridge driver for tread locomotion.

Motor requirements: sufficient torque to drive treads with the assembled robot weight (estimate 400–600g before chassis), shaft compatible with tread sprocket or wheel, voltage in the 5–12V range for practical power architecture. Geared motors (TT motors or N20 with encoders) are appropriate; encoders are recommended if closed-loop speed control is desired for straight-line driving.

H-bridge driver considerations: TB6612FNG is preferred over L298N (lower dropout, higher efficiency, more compact). DRV8833 is a compact alternative for lower-torque builds. MDD10A is appropriate if motor currents exceed 2A per channel. Confirm logic level compatibility with Pi Zero 2 W (3.3V).

Tread system: rubber tank treads with plastic sprockets are widely available in hobby robotics kits. Consider print-in-place treads in TPU if the Ender 3 Pro is configured for flexible filament. Track width and wheel spacing must be determined before body design can be finalized.

### 2. Arm and Head Servos

Select serial bus servos for left shoulder, right shoulder, and head rotation.

Feetech SCS0009 (same as GrowBot) or the Waveshare SC09 equivalent is the recommended baseline. These are half-duplex UART at 1 Mbps, report position and load, and chain on a single data bus. All three servos can share one UART bus on Pi-M, which simplifies wiring.

Confirm: 3 servos at estimated load draw (peak ~500mA each stalling) fit within the power budget.

Future expansion to elbow servos is in scope for a later phase. Design the servo bus and wiring to accommodate additional servos without rework.

### 3. Sensing Hardware

**VL53L1X Time-of-Flight (ToF):** Close-range obstacle detection on Pi-M. I²C (0x29 default address), 3.3V, up to ~4m range. Available as a breakout from Pololu or SparkFun. No alternative -- this is the selected sensor.

**MPU-6050 IMU:** Orientation sensing on Pi-M. Same as GrowBot (GY-521 breakout). I²C 0x68. No alternative -- consistent with reference.

### 4. Audio Hardware

One speaker, one amplifier, one microphone are required. The question is whether these are split between Pi-M and Pi-V or consolidated on Pi-V.

Recommendation: put microphone and speaker/amp on Pi-V (the cognition Pi). Audio I/O is part of the LLM interaction loop, not the motion control loop. Pi-M does not need audio. This simplifies Pi-M's responsibilities and avoids I²S pin conflicts.

Components: INMP441 I²S microphone, MAX98357A I²S amplifier, small 8Ω speaker (0.5–3W). Identical to GrowBot.

### 5. LED Ring

WS2812B LED ring (7+ pixels, 5V) on Pi-M for emotional and status expressiveness. Identical to GrowBot. Single GPIO data line. Requires root or appropriate permissions to drive.

The LED ring communicates robot state visually: online/offline, active/idle, emotion states. Color and pattern conventions are defined in Phase 04.

### 6. Power Architecture

This is the most critical departure from GrowBot. GrowBot runs everything off a single 1S LiPo → MT3608 boost to 5V, which is acceptable for two servos but insufficient for two DC motors plus three servos plus two Pis.

Design requirements:
- Separate power rails for motors and compute. Motor transients must not cause Pi brownouts.
- Two Pi Zero 2 W: ~200mA typical each, 400mA peak each.
- Two DC motors: current depends on selection; budget 1–2A per motor under load.
- Three servos (SCS0009): peak ~500mA each stalling; budget 1A typical for all three.
- Total compute + servo rail: ~2–3A budget; motor rail: sized to motor selection.

Recommended approach: 2S LiPo (7.4V nominal) with two separate regulation paths. A buck converter (LM2596-based or MP1584) steps down to 5V for compute + servos. Motor driver takes battery voltage directly (most H-bridges accept 7–15V input; the motors themselves set the floor). A capacitor bank across each 5V rail covers transient dips.

Alternatively: two separate 1S LiPo cells, one per rail. Simpler wiring, easier balancing, but two batteries to manage.

Document the chosen architecture with a wiring diagram before ordering. Do not replicate GrowBot's single-rail approach at this scale.

### 7. Body Design — FreeCAD

Johnny 5 reference aesthetics: tracked base, boxy torso, two arms with shoulder articulation, distinctive head with visor/eye element and antenna. The design must accommodate the actual selected hardware dimensions.

Design sequence:
1. Establish chassis dimensions from tread/motor selection.
2. Design tread base (motor mounts, tread sprocket cutouts, battery bay, Pi-M mounting).
3. Design torso (Pi-V mounting, camera mount in head, wiring routing).
4. Design arms (servo horn attachment points, range of motion clearance).
5. Design head (servo mount for rotation, camera mount, LED ring or eye element, antenna).

Ender 3 Pro build volume is 220×220×250mm. Large components must be split into printable pieces with alignment features (pins or keyed joints). Print in PLA for prototyping; upgrade stress-bearing parts to PETG for final build.

All FreeCAD source files go into the repo under `mechanical/freecad/`. STL exports for printing go into `mechanical/stl/`. Name files descriptively: `chassis_base_v1.stl`, `left_arm_upper_v1.stl`, etc.

### 8. BOM Document

Produce `BOM.md` in the repo root on the pattern of GrowBot's BOM.md. Columns: part, spec, qty, estimated cost (USD), supplier/notes. Include the GPIO pin map for both Pi-M and Pi-V. Include a power budget table.

---

## Recommended Session Start

Begin by reviewing the GrowBot BOM.md (https://github.com/britcruise9/GrowBot/blob/main/BOM.md) for component reference. Then work through each task above in order, starting with tread drive selection since chassis dimensions gate the body design.

---

## Open Questions for This Phase

- Encoder vs. no encoder on DC motors: does Andrew want closed-loop speed control for straight-line driving accuracy, or is open-loop adequate for V1?
- 2S LiPo vs. dual 1S: any preference on battery form factor or sourcing?
- Johnny 5 scale: rough target size? (e.g., fits on a standard desk vs. floor-roaming)
- Tread material preference: purchased rubber treads, printed TPU treads, or belt-and-sprocket?

---

## Session 01 — Engineering Log (2026-06-17)

### Open questions — resolved

- **Encoders:** Yes — N20-class geared motors with encoders (closed-loop driving + real velocity data for Phase 02 training).
- **Battery:** Single 2S LiPo, dual regulation.
- **Scale:** Floor-roaming, ~38–42 cm. Revised assembled-weight ceiling **1.6 kg**.
- **Tread material:** Printed TPU.

### Decision log (decisions + rationale)

- **Drive — Path A:** N20-class 12V/150:1 encoder motors + TB6612FNG, battery-direct on 2S. Chose compact/light/cheap/clean-logic over torque margin; accepts ~0.13 m/s and ~1× continuous torque margin. Contingent on the 1.6 kg ceiling.
- **Servos:** 4× SCS0009 (added a shoulder utility-box tilt servo) on one half-duplex bus via Waveshare Bus Servo Adapter (A). Arms kept light (≤50 g / ≤90 mm lever) to stay within rated torque and protect the weight budget.
- **Utility box** mounts to the torso shoulder with its own servo, so it never loads the arm servos. Navigation light (1 W) added on Pi-V as a camera aid.
- **Audio** consolidated on Pi-V (frees Pi-M's I²S). Needs a custom `simple-audio-card` overlay in Phase 01 (stock mic/amp overlays conflict).
- **LEDs:** mouth on Pi-V (SPI, audio-synced); eyes + battery gauge + status chained on Pi-M (SPI). Custom layout replaces the GrowBot ring.
- **Battery sensing** via ADS1115 — drives the gauge, a low-voltage cutoff, and telemetry.
- **Power:** three rails (motor battery-direct, 5V buck, 6V servo buck). Added inline 7.5 A fuse and a TB6612 STBY interlock (motors off on boot/crash). Servos must be regulated — 8.4 V full charge exceeds the SCS0009 7.4 V max.

### Deferred levers (not in V1 spend)

- Motor-rail boost to ~9–10 V if the drive proves underpowered.
- STS3215 servo upgrade if the arms lack authority.
- Path B (25D motors + higher-current driver) if Path A is inadequate.

### Attachments / docs for next session

- `CLAUDE.md`, this phase file, `BOM.md` (locked dimensions + pin maps).
- The two reference images Andrew shared (boombox-body photo; Lego-head photo) for head/torso proportions.
- **To produce before ordering:** a formal power wiring/harness diagram (the architecture is documented in `BOM.md`; a schematic should accompany it).

---

## Session 02 — Engineering Log (2026-06-18)

### What was built

Parametric build scripts in `mechanical/freecad/`, all driven by `params.csv` (single source of truth), with a FreeCAD-free `validate.py`, `mass_budget.py`, and matplotlib massing previews in `mechanical/preview/`:

- **Chassis/tread base** — tub 118×150×50, footprint 160×178, base height 68, drive at rear, 2 road wheels/side, prints in one piece. Belly 18 mm; axle at 23.5 mm (track band lifts the N20s clear). Rear trailing-caster pivot bosses + lean-ready waist reserve on the deck.
- **Torso** — tapered two-part keyed shell 110→96 ×90 ×165; Pi-V on the back wall; shoulders pitch on X; utility box on left; neck riser carries the head-yaw servo.
- **Arms** — single-DOF shoulder-pitch, fixed elbow, static 3-finger claw, ~24 g each; grip-ready (tendon channel/anchor/shoulder-axis path) for the V2 tendon gripper.
- **Head** — wide film-accurate 150×90×88 two-part shell; brass-ring eye domes + central camera in the bridge; mouth LED bar with speaker behind; **articulated twin brow blades** (offset outboard pivots, one bus servo → pinion to left gear direct, to right gear via an idler = mirrored roll, 3 poses); nod gimbal; antenna.

### Decision log (Session 02)

- **Stance:** parallel tracks confirmed (the splay in references reads as camera perspective).
- **Servos 4 → 6 SCS0009:** added head **nod** (#5) and articulated **brow roll** (#6), each mass-budget approved. Same bus (new IDs, no GPIO); 6 V rail ~3 A within the 5 A buck. +$22.
- **Stability:** rear **trailing swiveling sprung caster** (passive) added — rearward/incline tip margin 33°→54°, +33 g, +$5. Covers the case that matters at 0.13 m/s.
- **Powered waist — rejected for V1:** needs STS3215/lead-screw (SCS0009 can't hold the 531 g upper body: 5.4 vs 2.3 kg·cm), +116 g (worst-case 1662 g **over** the 1.6 kg ceiling), 6 V rail to ~4.5 A near the buck limit, +$26, for only ~7° decline gain not needed indoors. Value is expression, not stability. Interface left **lean-ready** (reserved pivot bosses + actuator pad) so it's a bolt-on V2.
- **Budgets:** mass ~**1321 g** (83% of ceiling, worst-case 1556 g under); height ~**395 mm** (in band); new-spend ~**$325–365**.

### Deferred levers (logged in BOM)

V2 tendon gripper (single-actuator underactuated claw); Dynamixel XL330 servo-standard alt; V2 powered waist; elbow servos; STS3215 arm-torque upgrade; motor-rail boost; Path B motors.

### Open threads

- Run `freecadcmd build_*.py` to produce STL/FCStd; inspect in FreeCAD for interferences (the in-sandbox checks are dimensional/mass, not solid booleans).
- Generate brow **gear teeth** (FreeCAD Gear workbench, module in `params.csv`) — currently modelled as gear blanks.
- Detail the press-fit eye-dome/camera inserts; drivetrain parts (sprocket/idler/road-wheel/TPU track) and the caster wheel/arm.
- Power wiring/harness schematic (carried over from Session 01).
- **Commit:** the `mechanical/` tree, `BOM.md`, `.gitignore`, and this phase update are written and ready — the commit failed only because the `.git` index/locks on the Nextcloud mount are permission-locked from the sandbox.

---

## Session 03 — Engineering Log (2026-08-20)

### Decision log (Session 03)

- **FreeCAD MCP adopted, running locally.** neka-nat addon, installed on the Windows desktop rather than the home-lab LXC: the RPC server runs inside FreeCAD's own GUI process, so it must live wherever the GUI does. This is what made run-the-geometry verification possible.
- **Verification moved from parameters into the build.** `validate.py` compares numbers to numbers and reported ALL CHECKS PASS while three defects reached the print bed. Boolean guards in `main()` — hole open *and* correct size, keep-out volumes, motor drop position, bearing shoulder present — are the ones that catch real defects. An overlapping fuse is legal and still returns one solid, so the single-solid check cannot see two features claiming the same volume.
- **Bearings live in the wheel hubs, not the tub walls.** A 10×4 mm 623ZZ pocket cannot fit a 2.4 mm wall at any sign. The BOM's 8× 623ZZ works out to two per idler wheel plus one per road wheel; the wall carries only a locating hole. Deletes the problem instead of adding a boss to engineer around it.
- **Idler runs one full-width 3 mm rod, not stub axles.** A stub has 2.4 mm of PLA resisting a 16 mm cantilever and will wallow out. A rod through both walls is constrained 118 mm apart and cannot cock. Ribs take a clearance notch, not a fit — locating on four holes would just add alignment risk.
- **Drive sprocket rides its own bearing, not the motor shaft.** The 9 mm output shaft cannot reach the 75 mm track centreline, and hanging a driven wheel off an N20 gearbox bushing is wrong regardless of reach. MR106ZZ pressed into the rear wall from outside, stepped ø6 hub set-screwed to the shaft over its full 9 mm. Wall takes the load, motor supplies only torque. Costs 2× MR106ZZ on the BOM.
- **Motor drops straight down.** With no shaft passing the wall, cradle length is set by pocket clearance plus the bearing shoulder rather than by insertion travel.
- **IMU moved off the centroid** to (35, −25). It and the battery bay both wanted the centroid and neither knew about the other. Gyro output is position-independent on a rigid body and the accelerometer's lever-arm term is a fixed correction, so the offset is cheaper than contorting the layout around it.
- **Pi-M shelf split into a separate print.** As one piece its underside needed support material in a tunnel obstructed by the battery bay ring. Open-topped ribs and a flat plate both print support-free; four M2 screws join them at assembly.
- **Battery bay ring trimmed clear of the cradles and left open aft.** The ring blocked hand access and the motor's rear wire exit. It is now shorter than the pack, so an aft end wall would land inside the pack footprint. Straps retain the pack; a drop-in aft stop is deferred until testing shows it is needed.
- **Drive motor fixed as Pololu #5218**, 150:1 HPCB 12V with 12 CPR encoder, back connector — closing the Session 01 "side vs back connector" question. Its connector needs a 3 × 11 mm relief in the −Y pocket wall, accepted knowing it grazes one cap screw (65% of surrounding material survives, so the screw is weakened rather than lost).
- **Hand edits in the FreeCAD GUI rejected as a workflow.** A rebuild overwrites the FCStd, and a GUI edit does not propagate to `params.csv`, so the defect returns on the next build. Physical measurement plus a description is the channel that has actually worked: every defect this session was found with the part in hand and fixed at the parameter level.

### Open threads

- **Drivetrain parts do not exist.** No build script produces the sprocket, idler, road wheel or TPU track. This is the only thing between the current tub and a rolling chassis.
- **Road wheels do not reach the track.** Stub-axle holes are cut at `AXLE` (23.5) but `roadwheel_dia` is 24, so the wheel bottom sits at 11.5 against a track inner surface at 3.5. Needs ø40 wheels or axles dropped to z 15.5. Decide inside the drivetrain work.
- **Caster mount does not connect.** `rear_pivot()` makes two bosses at x = ±16 bored along **Y**; `caster_arm()` has one eye at x = 0, also bored along Y. Nothing lines up, and a Y-axis pivot swings the arm sideways rather than fore-aft. Hanging straight back the wheel centre lands at z 23 with r 17, floating 6 mm off the floor.
- **Accepted as-is:** the floor lightening pocket's cut starts 0.05 mm above the belly surface, leaving a sub-layer skin that makes its depth ambiguous; the "fore and aft" floor pockets promised in that comment are one pocket.
- The Cowork remote-tools bridge drops `execute_code` intermittently while `list_documents` keeps working. Two false signals cost real time: a document in `list_documents` is usually left open from a previous session, and a fresh `.FCStd` timestamp with stale STLs is a GUI save, never a build — `main()` exports before it saves. Trust STL mtimes read from FreeCAD's own `os.listdir`; the sandbox bash mount lags badly on this repo.

## Session 04 — Engineering Log (2026-08-21)

The drivetrain exists and is guarded, the chassis carries it, and the assembled robot measures 1531 g against the 1.6 kg ceiling — 69 g of headroom, with the +25 % sensitivity on the remaining estimates landing at 1578 g, also under. `mass_budget.py` exits clean for the first time since Session 02 and `validate.py` passes every check. Every printed part in the robot is now measured from its built solid rather than estimated, and every build script refuses to export a part that is not a single solid.
### What was built

`mechanical/freecad/build_drivetrain.py`, driven from `params.csv` like the rest, producing five printable parts and running its checks against the real chassis solid:

* Drive sprocket — ø40 pitch, 10 lug pockets, stepped ø6 hub on the MR106ZZ in the rear wall, D-profile bore over the #5218 shaft with a grub collar in the 3 mm gap outboard of the wall. 25 g.
* Front idler — ø40, two 623ZZ in the hub, on the tensioning rod. 22 g.
* Road wheel — ø24, one 623ZZ inboard and a plain land outboard, print four. 11 g.
* TPU track loop — 28 mm × 3.5 mm closed band, 364.42 mm inner path, 29 centre lugs. 50 g.
* Idler tensioner carrier and axle collar — the tensioning hardware and the rod stops.

`build_chassis.py` reworked to match: road-wheel skirts, the idler slot and its carrier bosses, road wheels respaced, the drive hub clearance tightened to a plain-bearing land, deck and floor lightening, and the caster replaced by the anti-tip tail.
### Decision log (Session 04)

* Centre-guide lug track, not full-width teeth. One lug row down the middle of the band; the sprocket pockets drive it, the idler and road wheels ride the two smooth lands either side. This is what lets a ø24 road wheel and a ø40 sprocket share one track, and the lug row doubles as the derailment guide and as the axial stop that keeps the wheels on their rods.
* Lug pitch is the sprocket's tooth pitch by construction, and the loop closes at whatever straight run 29 of them demand — 119.38 mm, not the tub's nominal 120. Engagement error cannot accumulate around the loop; the 0.62 mm and all pretension are absorbed in the idler slot, where 1 mm forward is 2 mm of path and 0.55 % strain.
* Idler on a slot with a clamped carrier, not a fixed hole. The carrier bears on two bosses rather than the wall, because the wall is 2.4 mm and an M2 thread needs more. The old inner-face pads are gone with the fixed hole.
* Road wheels on a skirt. ø24 reaches the band only from a 15.5 mm axle line, which is 2.5 mm below the tub's underside, so the handoff's "either ø40 or axles down to z 15.5, params only" was not available: at 15.5 there is no wall to drill, and ø40 will not fit between a ø40 sprocket and a ø40 idler 120 mm apart. Each rod gets a local pad hanging off the wall, thickened inboard to 5.4 mm of bearing length.
* Road-wheel spacing became an explicit pitch. The old `wheelbase * 0.6` formula put two ø24 wheels 24 mm apart — exactly tangent. Nothing in the parameter sheet showed it; the first build-time rim-gap check caught it on the first run. At 40 mm pitch the four ground contacts fall in even quarters along the run.
* Rear caster became a fixed anti-tip tail. It never assembled — pivot bosses bored along Y at x = ±16 against an arm eye at x = 0 — and a ground-riding caster would scrub on every tank turn and lift weight off the tracks for a margin that comes from where the roller sits, not from it being sprung. A level boom holding a ø25 roller 4 mm clear engages at about 2° of rearward pitch, keeps the 33°→54° margin, and drops the spring, the pivot and 7 g.
* Everything above was verified by building it. Two defects (the tangent road wheels, the obstructed rod) were found by boolean guards on the first run and would have survived any amount of parameter arithmetic.
* One electronics shelf, on columns. The Pi-M shelf runs 38 mm further aft and carries the IMU as well as the Pi, so the whole tub electronics stack builds up outside the tub and drops in on six screws. Its two solid 8.4 × 73 mm ribs became three columns a side — a rib extended to 111 mm would have been 58 g, columns are 23 g — and the gaps between columns are where wiring crosses underneath. Three passthrough slots in the plate: two beside the Pi, one aft for the battery and motor loom. Net about 11 g lighter than the ribs it replaces.
* The IMU came back to the centreline. It was pushed to (35, −25) in Session 03 only because the battery bay ring owned the middle of the tub floor; off the floor there is nothing to dodge, so the accelerometer's lever-arm correction disappears with it. This also resolved a defect I introduced: one of the four floor lightening windows sat directly under the old floor pad, leaving two of its screws over a hole. Those windows are weight-only, they serve no mechanical function, and nothing mounts over them now.
* Herringbone treads, relieved out of the band rather than added onto it. The ground face was smooth. 24 chevrons, 1.5 mm deep, 3.5 mm ribs at 25° from transverse. Cutting them out of the 3.5 mm envelope instead of standing them proud keeps the tip radius at 23.5, so ride height, rolling radius and ground speed are untouched — proud grousers would have taken about 6 % off a drive with roughly 1× continuous torque margin. The continuous band drops to 2.0 mm, which nearly halves the outer-fibre bending strain at the sprocket and so improves flex-fatigue life. The 25° arm angle is a printing constraint before it is a styling one: the loop prints with its width vertical, so the arm angle is also its lean off vertical.
* Segmented chevron arms, after the tread guard caught a floating-geometry defect. Built as two straight 15 mm bars, each arm lay tangentially on the 22 mm valley radius: its inner face left the band surface 6.6 mm from the root, so 1.6 mm of every arm end floated free of the band on every wrapped section and the tip stood 1.36 mm proud of the tip radius. The single-solid check cannot see that, because the bar is attached over most of its length, and it was the tread-tip envelope guard that failed. Each arm is now five short pieces placed on their own path points, which takes the worst chord to 0.2 mm and keeps every piece attached. The leaning pieces also overhang both track edges by 0.74 mm, so the finished loop is trimmed to its own width.
* No openings in the tub floor. The four floor lightening windows are gone: 6.7 g is not worth an opening straight into the electronics bay from ground level. The battery bay ring was the obvious place to take the weight from instead, and it cannot fund it — the entire ring is 6.8 g before its strap slots, so deleting it outright would barely break even, and perforating the wall that retains a LiPo for about 1.5 g is a poor trade. The side walls funded it instead: six blind pockets a side rather than two, 1.4 mm into a 2.4 mm wall, worth 6.7 g with no opening at all. The tub came out at 161.1 g either way — an exact wash.
* The motor pockets open the tub floor and cannot be closed by deleting a cut. A ø12 motor on a 23.5 mm axle line has its belly at z 17.5, below the tub's own underside at 18.0, so the bore cuts the floor out from under each motor and the motor protrudes 0.5 mm into open air. That is 525 mm² of genuine through-opening, against 2,240 mm² for the four windows that were removed. It is largely blocked in service — the motor body fills the bore and the retention cap closes the slot above it — so the path into the electronics bay is poor, but it is a path. A 3 mm skirt under the bore footprint would close it for about 3.9 g; deferred, with a strip of foam tape at assembly as the zero-mass alternative.
* The anti-tip roller got a tyre. It was a bare PLA cylinder, which is the wrong thing on the one part whose entire job is to catch the robot — hard plastic skitters on a hard floor rather than biting, and it is loud doing it. It is now a ø20 PLA hub inside a ø25 TPU 90A tyre, retained by a 0.25 mm interference fit and a lip at each hub edge that sits well inside the tyre's outer diameter so it never reaches the floor. The tyre carries the overall diameter, so the 4 mm float and the tip-margin geometry are untouched, and it prints in the filament already specified for the tracks, so it costs no BOM line — only a second tiny print. 5.6 g assembled against 6.0 g for the bare roller.
* Shell walls 2.4 -> 2.0 mm on both torso and head. A 150x90x88 shell at 2.4 mm is inherently 206 g and there was nowhere else on the robot worth more than about 25 g. 2.0 mm is five perimeters at 0.4 and keeps a sensible margin on a torso carrying both arms, the head and four servos. Torso 239 -> 218 g, head 208 -> 181 g. Less than the 75 g the wall alone would have given, because the same pass added a shoulder deck, four split pads and four deck-bolt ribs that the design needed and did not have.
* Six defects in the torso and head, found by reading the scripts rather than by any check. The left shoulder had no shaft hole and no horn recess at all — `xface - sgn*(WALL+3)` is right-handed only, so on the left the cut began inboard of the wall and ran further inboard, and the left arm servo had no way through the shell. Its mount bosses ended flush against a lofted taper, meeting it along a line rather than an area, so they never fused. The deck bolt bosses were columns standing in the middle of a hollow shell. The neck riser sat over the open top of the torso with its whole ø34 footprint in mid-air, carrying the head, the nod servo and the yaw servo. `lightening()` cut a ø2.8 x 26 mm rod, not a pocket: a through-hole in the right wall and a blind bore under the left skin. And the Pi-V standoffs were anchored to one constant y while the back wall leans 6 mm over the torso height, putting the upper pair through the outer skin.
* Registration pins need somewhere to be. Both scripts put their split-key pins in free air — the torso's 12 mm inboard of the outer face, the head's 6 mm inboard of a wall that starts at 73 — because the split plane cuts a hollow shell and the only material on that face is two 2 mm side-wall strips. Moving them along y, which was the first fix, did not change that. Both now sit in pads that straddle the split, so each half keeps its own share.
* A boolean can be too tight as well as too loose. The first shoulder deck was sized to the torso cavity exactly, and that cavity is a lofted taper: plate and wall agreed to within 0.04 mm across the plate thickness, overlapping on one side of that and gapping on the other. FreeCAD ground on the slivers for minutes and never returned. Every mating feature here now takes a deliberate bite — 1.5 mm for bosses, 0.6 mm for the deck, chosen to leave 1.36 mm of skin outboard.
* Mass is now measured, not estimated. `components.csv` carries built-solid volumes for every printed part and those lines are marked firm rather than soft.

### Open threads

* ~~Over the ceiling by 18 g.~~ Closed this session at 1531 g: shell walls to 2.0 mm on torso and head, and two double-counted lines removed from `components.csv` — the neck riser (52.9 g) is fused into the torso solid and the head nod ears (7.1 g) into the head, so both were being paid for twice.
* ~~`build_torso.py` and `build_head.py` export floating islands.~~ Closed this session. Both now carry the single-solid guard and both halves of both parts build as one solid.
* `mass_budget.py` has been unrunnable since Session 02 — `components.csv` had an unquoted comma in "Brow blade (PLA, thin)", so `float()` hit the wrong column. Fixed this session. Any budget figure quoted between Session 02 and now was not produced by that script.
* Sprocket overhang. The sprocket's centre sits 16 mm outboard of a single 3 mm-wide MR106ZZ. The loads are small enough that it should hold, but it is the least-supported joint in the drivetrain and the first thing to look at if the drive feels rough on the bench.
* Assembly order: the sprocket grub screw must be set before the track goes on — the track band covers the only access to it.
* Everything in this session is built and guarded in FreeCAD: both `main()` calls run clean and the drivetrain guards have now been checked against the reworked tub. The FreeCAD MCP's GUI dispatch jammed for a stretch mid-session (`list_documents` answering while `execute_code` and `create_document` both timed out at 60 s, surviving a restart) and cleared on its own. The addon predates `get_rpc_status`, which would diagnose it in one call; worth updating.
* If the underside is ever meant to be sealed, the motor-pocket openings are the only remaining path and the fix is a parameter away. `build_chassis.main()` now guards the underside: it probes just inside both faces of the floor and fails if more is open right through than the motor pockets account for, so no future lightening pass can reopen the floor by accident.
* Screen accuracy of the track pattern is a Phase 06 question. The reference photographs show transverse rectangular grouser pads on the film tracks, not the herringbone adopted here — the herringbone was chosen as a design preference and for its lateral bite in tank turns, and swapping the pattern later is a parameter change, not a redesign.
* Not yet done: reprint the tub, print the drivetrain, update `preview/` massing for the new parts, and the power wiring/harness schematic still owed from Session 01.

### Deferred to Phase 06 (cosmetic pass)

* Screen accuracy of the track pattern. The reference photographs show transverse rectangular grouser pads on the film tracks, not the herringbone adopted here; swapping the pattern is a parameter change, not a redesign.
* Fine circumferential ribs on the anti-tip tyre if the smooth wall reads wrong up close. Structurally it should stay smooth.
* Brow gear teeth, currently pitch-diameter blanks, and the press-fit eye-dome and camera inserts.

### Known weaknesses logged, not fixed

* The torso's four M3 split screws pass through the front wall, cross 90 mm of open interior and land in the back wall. That is registration, not clamping, and it should be revisited when the torso is first assembled.
* The sprocket sits 16 mm outboard of a single 3 mm MR106ZZ. Loads are small enough that it should hold; it is the least-supported joint in the drivetrain and the first thing to look at if the drive feels rough on the bench.
* The motor pockets open the tub floor by 525 mm² and cannot be closed by deleting a cut, because the motor's belly sits below the tub's underside. Largely plugged in service by the motor and its cap. A 3 mm skirt would close it for 3.9 g; foam tape at assembly costs nothing.

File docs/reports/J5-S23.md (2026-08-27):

# J5-S23 — D9, remediation of what S22 turned up

**Session:** J5-S23. Sonnet, Standard thinking, Medium effort.
**Date:** 2026-08-27.
**Branch:** `docs/s22-remediation`, off `main`. Not created by this session; it is in the
command block in section 6, along with every other git write.
**Dispatch:** D9. Three unrelated corrections that share nothing but their size:
O22's file half, O23, and O27's `.gitignore` half.
**Integration lock:** held. No other session ran.

This report contains no state updates. `PROJECT_STATE.md` was not edited.

---

## 1. Preconditions

**The connected folder is the wrong folder, again.** `C:\Users\apsus\Nextcloud\Documents\VS Code\Johnny5\Johnny 5`
mounts and is empty. `device_request_folder_access` for `C:\dev\johnny5` was the first act of
the session and was granted. Every session so far has hit this and this one did too.

**`main` carries the S22-O state commit.**

```
$ git cat-file -p main:PROJECT_STATE.md | grep -c "| \*\*O22\*\* |"
1
```

**`main` is ahead of `248a41d`, as expected.** `git for-each-ref` puts `main` at `9765f71`,
and `HEAD` is on `main` at the same SHA. The log from the top:

```
9765f71 docs: verify J5-S22 close-out, log Andrew's CAD commits, open O22-O27
248a41d docs: add the Pi-V runtime document
ecb244f hw: print the track loop as a circle rather than in its running shape
23157ef hw: carry the IMU on a breadboard aft on the Pi-M shelf
```

**No lock files, at open or at close.**

```
$ find .git -maxdepth 2 -name "*.lock"
$ echo $?
0
```

**Working-tree baseline, recorded before anything was written.** This is what the
"nothing else modified" claim in section 3 is read against.

```
$ git --no-optional-locks status --porcelain
 D mechanical/freecad/drivetrain_v1.20260821-142329.FCBak
 M mechanical/freecad/drivetrain_v1.FCStd
?? mechanical/freecad/chassis_assembly_v1.20260826-141152.FCBak
?? mechanical/freecad/drivetrain_v1.20260826-203851.FCBak
```

All four lines are FreeCAD's own. The ` D ` line is exactly the symptom O27 describes: a
tracked `.FCBak` that FreeCAD's ordinary backup rotation replaced. Nothing was added with
`git add -A` and nothing in this baseline was touched.

---

## 2. What was done

### 2.1 `.env.example` — the literal LiteLLM key replaced with a placeholder

`LITELLM_API_KEY=sk-ft-osuRqKu2Eldav3HgAVw` is now `LITELLM_API_KEY=<set-on-litellm-proxy>`,
in the same angle-bracket form `MQTT_PASSWORD=<set-on-broker-deploy>` already uses in the same
file. The comment block above the LiteLLM stanza gains three lines:

```
# The key itself is a secret and is not carried here: the real value lives in
# the per-Pi .env only, which .gitignore already covers. This file holds a
# placeholder, in the same form as MQTT_PASSWORD below.
```

`.gitignore` line 6 is `.env`, so that claim is true as written and was checked rather than
assumed.

Nothing else in the file changed. `LITELLM_ENDPOINT`, `LITELLM_MODEL` and `LITELLM_TIMEOUT`
are untouched, and so is the existing rationale paragraph — the 60.0 s timeout's justification
is load-bearing and is repeated at length in `docs/HARDWARE_pi_v_runtime.md`.

The file's working-tree copy was CRLF and is now LF. That is O21 territory: the blob was
already LF and is unaffected either way, but the definition of done requires `w/lf`, so the
whole file was normalised in the same write rather than left mixed. This is one of the
75 CRLF working-tree files O21 counted; 74 remain, and O21's recommendation to leave them
alone is not disturbed by normalising a file that was being rewritten anyway.

**This does not close O22.** The key is in the repository's history from `22ad422` on
2026-06-20 and the remote is public; editing the file forward removes nothing from history.
Rotation on the AOS proxy is the remediation, it is Andrew's, and it is still open.

### 2.2 `BOM.md` — the mass figure re-quoted from the script

Lines 173 and 181, the only two lines in the file that carried the superseded figure.
`mechanical/preview/mass_budget.py` was run by this session and its output is in section 3;
no figure here was copied from the dispatch brief or from `PROJECT_STATE.md`.

Line 173 keeps O13's framing — the script is named as the source, the entry stays struck
through — and now reads `**1542 g against the 1.6 kg ceiling**`, 58 g of headroom, 1597 g at
+25 %. One clause was added naming the provenance of the move; its wording differs from what
the brief specified, and section 5 thread 1 says why.

Line 181, the Phase 00 gate paragraph, carries the same three figures and gains a short clause
naming the script and saying the figure moves when the geometry does. That clause is there
because the paragraph is headed **Met 2026-08-21** and now quotes a post-gate number: without
it the paragraph reads as though 1542 g was the figure at gate close, which it was not. This
is a judgement call inside the brief's scope, not an expansion of it.

The file is 183 lines before and after and the diff is exactly two lines:

```
$ diff --unified=0 <HEAD:BOM.md> BOM.md | grep "^@@"
@@ -173 +173 @@
@@ -181 +181 @@
```

### 2.3 `.gitignore` — a pattern for FreeCAD's `.FCBak` sidecars

Three lines appended, keeping the file's existing comment-then-pattern shape:

```
# FreeCAD backup sidecars. Rotated on every save and holding nothing the .FCStd
# history does not; see PROJECT_STATE.md section 7, O27.
*.FCBak
```

The pattern is unscoped rather than `mechanical/freecad/*.FCBak`. All four tracked sidecars
live in `mechanical/freecad/`, but a `.FCBak` is never wanted anywhere in this repository and
FreeCAD writes them beside whatever `.FCStd` is open, so the narrower pattern would only be a
future gap. `.gitignore` already mixes both styles — `*.log` global, `simulation/**/*.mjb`
scoped — so neither is against convention.

**The pattern does not untrack what is already tracked.** The four files named in O27 need a
`git rm --cached`, which is a git write and is therefore in section 6's block, with its
one-line rationale attached to the commit message.

One immediate effect is visible in `git status` already: the two untracked sidecars in the
baseline, `chassis_assembly_v1.20260826-141152.FCBak` and `drivetrain_v1.20260826-203851.FCBak`,
stopped being reported the moment the pattern landed.

---

## 3. Definition of done

Every item the brief named, with real output.

**No `sk-ft-` outside the archive, the reports and the state file.**

```
$ git grep -n "sk-ft-" -- . ':!docs/archive' ':!docs/reports' ':!PROJECT_STATE.md'
$ echo $?
1
```

No output, exit 1 — git grep exits 1 on no match. The three excluded paths still carry the
value: `docs/archive/INITIATING_PROMPT_2026-08-22.md` line 176, `docs/reports/J5-S22.md`
line 336 and `PROJECT_STATE.md` line 430, all of them deliberate records of the exposure.

**The `BOM.md` figure is the script's own output.** `mass_budget.py` run this session:

```
  Johnny 5 mass budget   (ceiling 1600 g)
  --------------------------------------------------
    base build (4 servos)         1418 g
    head nod (5th servo)            58 g
    brow roll (6th servo)           40 g
    rear anti-tip tail              26 g
  --------------------------------------------------
  ASSEMBLED TOTAL                 1542 g   (96.4% of ceiling)
  headroom                          58 g
  worst-case (+25% printed)      1597 g   UNDER ceiling
  --------------------------------------------------
  VERDICT: within ceiling with margin
```

Run twice, from two places, to the same numbers: once in a `$HOME/scratch` copy of
`mechanical/preview/` and `mechanical/freecad/` whose four input files `md5sum` identical to
the mount, and once in place from the mount itself.

```
$ grep -c 1531 BOM.md
0
```

**The `.gitignore` line is what ignores the sidecars.**

```
$ git check-ignore -v --no-index mechanical/freecad/chassis_assembly_v1.20260821-143150.FCBak
.gitignore:31:*.FCBak	mechanical/freecad/chassis_assembly_v1.20260821-143150.FCBak
$ git check-ignore -v --no-index mechanical/freecad/drivetrain_v1.20260821-142329.FCBak
.gitignore:31:*.FCBak	mechanical/freecad/drivetrain_v1.20260821-142329.FCBak
$ git check-ignore -v --no-index mechanical/freecad/head_assembly_v1.20260619-220703.FCBak
.gitignore:31:*.FCBak	mechanical/freecad/head_assembly_v1.20260619-220703.FCBak
$ git check-ignore -v --no-index mechanical/freecad/torso_assembly_v1.20260619-220703.FCBak
.gitignore:31:*.FCBak	mechanical/freecad/torso_assembly_v1.20260619-220703.FCBak
```

`--no-index` is required and is not a workaround: plain `git check-ignore` skips tracked
paths by design and prints nothing for all four, which is a statement about their being
tracked and not about the pattern. On the two sidecars that are untracked, plain
`git check-ignore -v` names the line without any flag:

```
$ git check-ignore -v mechanical/freecad/drivetrain_v1.20260826-203851.FCBak
.gitignore:31:*.FCBak	mechanical/freecad/drivetrain_v1.20260826-203851.FCBak
```

**Test suite.** `pytest` is absent from a fresh session shell, so
`pip3 install pytest --break-system-packages` was run first; it installed pytest 9.1.1.

```
$ python3 -m pytest -q
................................................                         [100%]
48 passed in 0.40s
```

**Harness net check, exit 0 with all six checks.**

```
$ python3 scripts/check_harness_nets.py
  [1] gpio exists     OK   24 GPIO references, all in their Pi's pin map
  [2] gpio unique     OK   Pi-M 18 claimed, Pi-V 6 claimed
  [3] rails           OK
        worst case at the fuse    6.65 A of 7.50 A fuse (11 % margin)
  [4] endpoints       OK   145 endpoint references resolve to 24 BOM line items
  [5] passive values  OK   0.1 µF, 100 kΩ, 1000 µF, 330 Ω, 47 kΩ
  [6] drawing parity  OK   64 nets, document and SVG identical

ALL CHECKS PASS
$ echo $?
0
```

**Preview validation.**

```
$ python3 mechanical/preview/validate.py
  ...
  footprint 160x178 mm | height 395 mm | head 150x90 mm
  ALL CHECKS PASS
$ echo $?
0
```

**Line endings on all three touched files.**

```
$ for f in .env.example BOM.md .gitignore; do printf "%s CR=" "$f"; tr -cd '\r' < "$f" | wc -c; done
.env.example CR=0
BOM.md CR=0
.gitignore CR=0

$ git ls-files --eol .env.example BOM.md .gitignore
i/lf    w/lf    attr/                 	.env.example
i/lf    w/lf    attr/                 	.gitignore
i/lf    w/lf    attr/                 	BOM.md
```

A working-tree CR count is not evidence about a commit — O21 — so the blob-level check the
brief names was run as well. `git hash-object --path <f> <f>` applies the repository's filters;
`git hash-object -t blob <f>` does not. Equal hashes mean the filters have nothing to do,
which means the content going in is already LF.

```
.env.example  path=0b67dcca0d72d3c9c56959051c4e798260474ba0  blob=0b67dcca0d72d3c9c56959051c4e798260474ba0  match=YES
BOM.md        path=ef0334ef5273b047fb55246682382c07ec6b5588  blob=ef0334ef5273b047fb55246682382c07ec6b5588  match=YES
.gitignore    path=1f01f9b12cfb1459468ca31d944c28834c6e20c9  blob=1f01f9b12cfb1459468ca31d944c28834c6e20c9  match=YES
```

The `.env.example` and `.gitignore` hashes above are what those blobs must be after Andrew's
commit lands; `BOM.md` likewise. They are worth re-checking with `git rev-parse` on the
committed tree rather than taken on this report's word.

**Nothing else modified.** Against the baseline in section 1:

```
$ git --no-optional-locks status --porcelain
 M .env.example
 M .gitignore
 M BOM.md
 D mechanical/freecad/drivetrain_v1.20260821-142329.FCBak
 M mechanical/freecad/drivetrain_v1.FCStd
```

Three additions, all of them this session's. The `drivetrain_v1.FCStd` modification and the
` D ` sidecar line are the baseline's and are untouched. The two `??` sidecar lines are gone,
not because anything happened to the files but because `*.FCBak` now covers them.

**Greps for superseded strings excluded `docs/archive/` and `docs/reports/`**, as the brief
requires, in the `sk-ft-` check above. The `1531` grep is `BOM.md`-only by the brief's own
definition and needed no exclusion; for the record, `1531` also survives in `PROJECT_STATE.md`
and in the S18 and S22 reports, all of them correct history.

---

## 4. Decisions taken, with rationale

**The `.FCBak` pattern is unscoped.** Reasoning in 2.3. The narrow form would have satisfied
the definition of done identically and left a gap the first time a `.FCStd` is opened outside
`mechanical/freecad/`.

**`--no-index` on `git check-ignore` for the four tracked files.** Plain `git check-ignore`
prints nothing for a tracked path whatever `.gitignore` says, so the plain form would have
been evidence of nothing. Both forms are in section 3 so the distinction is visible rather
than hidden behind a flag.

**Line 181 gained a clause the brief did not ask for.** It quotes a post-gate figure inside a
paragraph headed with the gate date. Six words naming the script and saying the figure moves
is cheaper than leaving a reader to conclude the Phase 00 gate closed at 1542 g.

**The provenance clause on line 173 does not say what the brief said to say.** See thread 1.

**`.env.example` normalised to LF in full rather than in the edited lines.** A file half CRLF
and half LF is worse than either, and the definition of done requires `w/lf` on it.

**Nothing was written to `PROJECT_STATE.md`**, and the report carries no state updates. The
corrections in section 5 are for the orchestrator to apply or reject.

---

## 5. Open threads discovered

**1. O23's stated cause is half wrong, and so is the dispatch brief's.** Both say the figure
moved "because of `23157ef` and `ecb244f`". It did not. `ecb244f` moved no mass at all.

`mass_budget.py` was run at three revisions, from clean `git show` extractions of its four
inputs, in `$HOME/scratch`:

```
=== 23157ef^ ===
  ASSEMBLED TOTAL                 1531 g   (95.7% of ceiling)
  headroom                          69 g
  worst-case (+25% printed)      1578 g   UNDER ceiling
=== 23157ef ===
  ASSEMBLED TOTAL                 1542 g   (96.4% of ceiling)
  headroom                          58 g
  worst-case (+25% printed)      1597 g   UNDER ceiling
=== ecb244f ===
  ASSEMBLED TOTAL                 1542 g   (96.4% of ceiling)
  headroom                          58 g
  worst-case (+25% printed)      1597 g   UNDER ceiling
```

The whole 11 g is `23157ef`: `+IMU carrier breadboard,sensor,1,8,base,1` and the Pi-M shelf
plate from `1,20,base,0` to `1,23,base,1`. `ecb244f` touched
`mechanical/preview/components.csv` — which is why it looks causal in a `--stat` — but changed
only the TPU track loop's note, leaving its 36 g exactly as it was, because band mass depends
on path length and thickness and not on the shape the loop is printed in. The commit says as
much in the note it added.

`BOM.md` line 173 now states this rather than the brief's version. **Recommend O23's text be
corrected in the same pass that closes it**, so the register does not carry a causal claim the
repository contradicts. This is section 4 of `docs/ORCHESTRATION.md` working as designed —
every mass figure traced to the script that produced it — and it caught a wrong attribution
in the item that was itself about a wrong figure.

**2. FreeCAD's numbered backups are not covered.** `*.FCBak` catches the sidecars FreeCAD
writes by default. FreeCAD can also be configured to keep `.FCStd1`, `.FCStd2` and so on
alongside the document, and none of those match any pattern in `.gitignore`. None exist in
the tree today. If Andrew's FreeCAD ever has that preference set, the same class of noise
comes back under a different name. One extra pattern would pre-empt it; it was left out of
this session because nothing in the repository evidences the setting and guessing at a
`.gitignore` line is how patterns accumulate that nobody can justify later.

**3. The four `.FCBak` blobs stay in history after the `git rm --cached`.** They are FreeCAD
document snapshots of superseded states, between 80 KB and 540 KB each on the evidence of
their `.FCStd` siblings. Untracking stops them growing; it does not shrink the repository.
No action recommended — a history rewrite is rejected for O22 on stronger grounds than
these files could ever justify.

**4. `ORCHESTRATION.md` section 7's Python-import hazard did not reproduce.** "Python cannot
import modules from the mounted repo directory (`OSError [Errno 22]` in `_fill_cache`)".
`mass_budget.py`, `validate.py` and `check_harness_nets.py` all ran in place from the mount
this session, and `mass_budget.py` gave byte-identical output to the scratch copy. The scratch
route was used anyway, and both runs are in section 3, because a hazard that has bitten before
is not disproved by one session where it did not. Worth a note against that bullet rather than
a deletion of it: the failure mode appears to be intermittent or to have been fixed under the
session, and something that only sometimes fails is more dangerous than something that always
does.

**5. `.env.example` still carries live infrastructure detail that is not a secret and is not
in scope.** The endpoint `http://192.168.1.223:4000/v1`, the broker at `192.168.1.227:1883`
and the username `johnny5` are all in a public repository. They are RFC1918 addresses and the
project has decided they are acceptable — O22 says so explicitly and scopes the exposure to
the credential. Recording it here only so that no future session reads the placeholder edit as
having made the file secret-free in a broader sense than it did.

---
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

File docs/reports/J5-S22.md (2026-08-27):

# J5-S22 — Pi-V runtime document (D8)

Worker session. Scope was `docs/HARDWARE_pi_v_runtime.md` and nothing else. Maintenance, not
progress on Task 6b.

**Session config:** Sonnet, Standard, Medium, as briefed.
**Branch:** `docs/pi-v-runtime` off `main`. Not created by this session; it is in the command
block in section 6, which is Andrew's to run.

---

## 1. Preconditions

Four of the five held exactly. **One did not hold in the form the brief stated it, and the
reason is worth reading before anything else in this report.**

**The dispatch hazard was real again, as briefed.** The connected folder
`C:\Users\apsus\Nextcloud\Documents\VS Code\Johnny5\Johnny 5` is empty.
`device_request_folder_access` for `C:\dev\johnny5` was the first call of the session and was
granted. Every session through S22 has now hit this.

**`main` has moved since the brief was written.** The brief's precondition reads: "`main`
carries S21's commit, so `git log --oneline -3` shows a commit whose message mentions the 1807
encoder figure". The first clause is true. The second is not, because two further commits have
landed on `main` since:

```
$ git --no-optional-locks log --oneline -8
ecb244f hw: print the track loop as a circle rather than in its running shape
23157ef hw: carry the IMU on a breadboard aft on the Pi-M shelf
38569a1 docs: verify J5-S21 close-out, close D7 and O16-O20, open O21
10650f2 docs: clarify the 1807 encoder figure, simplify the bench wiring key, ignore .claude/
91aab43 docs: verify J5-S20 close-out, requalify O16 and O18, re-queue D7 as J5-S21
a1f0111 docs: remove the five root project-memory notes and their index
382ee10 fix: Pi-M setup script installs gpiozero and lgpio from apt, and targets the venv that exists
ebdea9e docs: verify J5-S19 close-out, close O16 and O18, queue the maintenance session
```

S21's commit is `10650f2` and it is on `main`; the orchestrator's state commit `38569a1` is on
`main` behind it. Both are fourth and third rather than first and second, because Andrew
committed `23157ef` and `ecb244f` on the evening of 2026-08-26 after the S21-O turn ended.
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

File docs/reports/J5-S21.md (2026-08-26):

# J5-S21 — Documentation and drawing maintenance (D7, re-dispatch)

**Outcome: complete. All four scope items done. O19, O17 and O20 are fixed in the working
tree and await Andrew's command block; O4 is answered, and the answer is no.**

Date: 2026-08-26. Session config as dispatched: Sonnet, Standard, Medium. Branch to be cut:
`docs/drawing-and-figure-fixes` off `main` @ `91aab43`. This session holds no integration
lock and made no git writes.
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

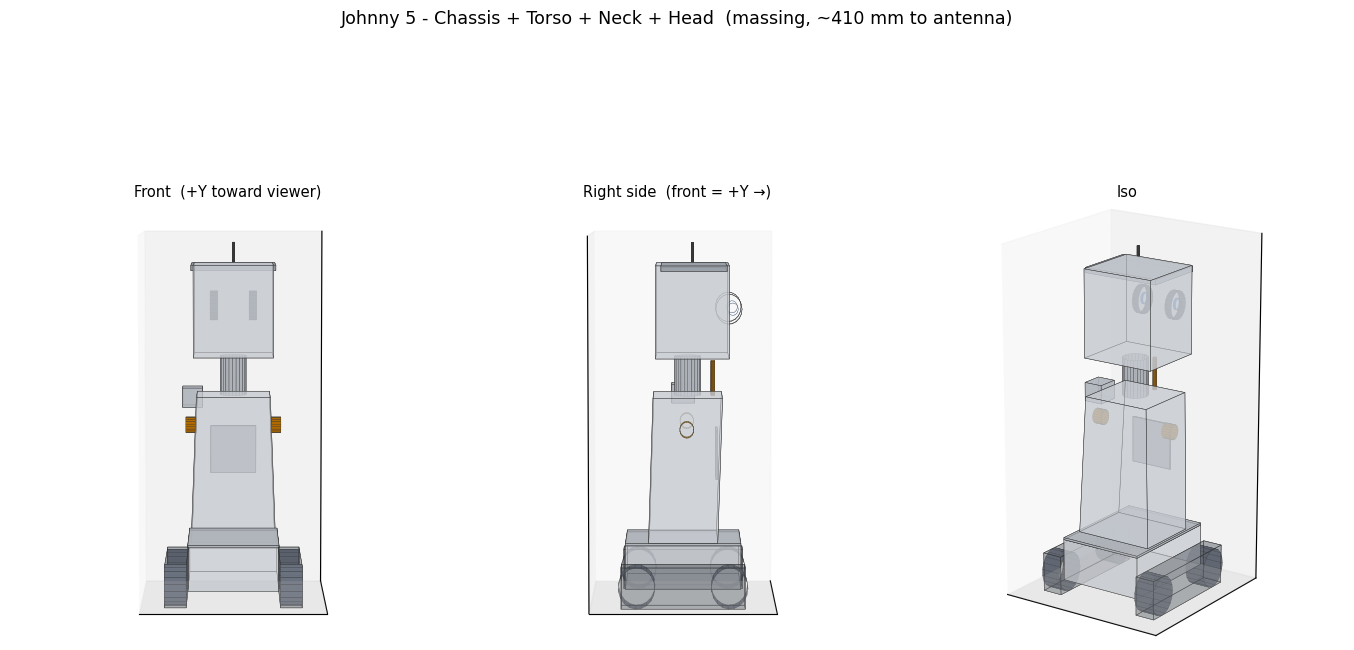
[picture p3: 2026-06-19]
mechanical/preview/robot_massing_v1.png

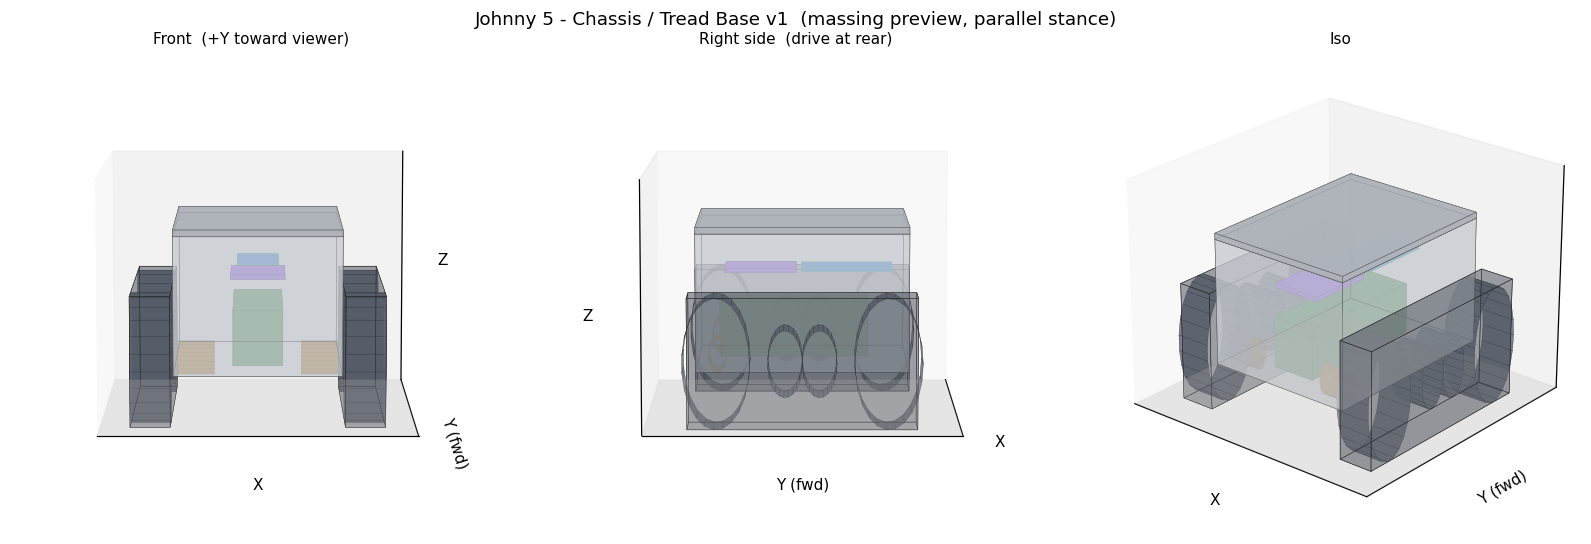
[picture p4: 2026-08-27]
mechanical/preview/chassis_massing_v1.png

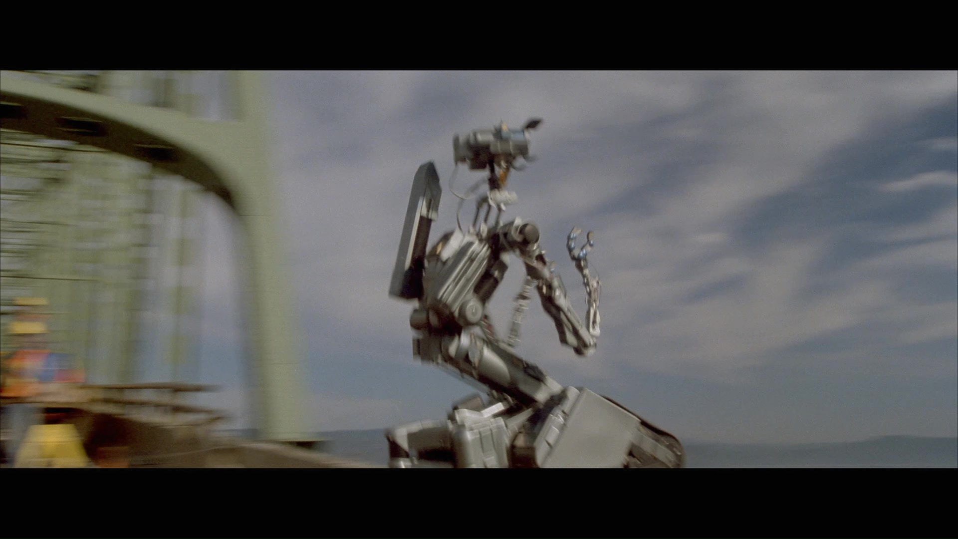
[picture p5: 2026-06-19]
reference_images/1cd8de6651d719f9d6dd72706dc2538a-o.jpg

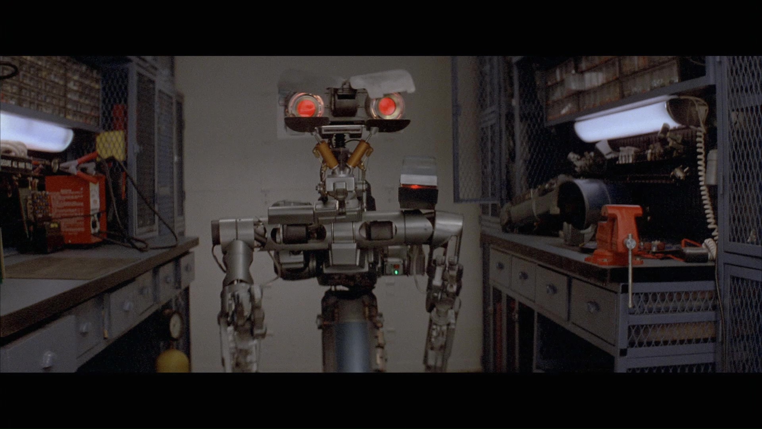
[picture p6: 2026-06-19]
reference_images/dc4b2eea5dfb962b06b9ecccfcd7a59b-o.jpg

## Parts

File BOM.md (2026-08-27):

# Johnny 5 — Bill of Materials (Phase 00)

**Status:** Approved by Andrew, 2026-06-17. BOM half of the Phase 00 gate is met.
**Target:** Floor-roaming, ~38–42 cm tall, assembled-weight ceiling **1.6 kg**.
**Battery architecture:** Single 2S LiPo, three rails (motor battery-direct, regulated 5V, regulated 6V).

Costs are estimates in USD, parts only, excluding shipping and items Andrew already owns.

---

## 1. Tread Drive

| Part | Spec | Qty | Est. cost | Supplier / notes |
|---|---|---|---|---|
| Drive gearmotor | **Pololu #5218** — 150:1 Micro Metal Gearmotor HPCB 12V with 12 CPR Encoder, **back connector** (N20-class, 12 mm) | 2 | $65 | Selected Session 03 after test-fitting; both sides identical. Back-connector variant confirmed (was an open question). Exact ratio 150.58:1 → 1807 counts/output-rev at 4× quadrature, which is **not** the operative figure: `gpiozero.RotaryEncoder` decodes 1×, so `COUNTS_PER_OUTPUT_REV` is **451.74** (3 cycles/motor-rev × 150.58), measured 450.6 at S10 (see `simulation/chassis/TUNING.md`). 9 mm × 3 mm D-shaft; gearbox cross section 10×12 mm. Run battery-direct at ~7.4 V (≈62% of 12 V rating). 6-pin JST SH encoder cables are supplied with the motor and need no line item of their own (confirmed with the parts in hand, 2026-08-25); the connector is recorded in `docs/HARDWARE_power_harness.md` so a replacement can be identified. An earlier note here saying they are sold separately was wrong. **Part number and price corrected 2026-08-25 (O6, session J5-S17):** the Pololu catalogue prices #5218 at **$32.45 each**, so $65 for the pair rather than the $46 previously carried. #5219 is the same 150:1 HPCB 12 V 12 CPR motor with a **side** connector at the same price; the chassis pocket carries a 3 × 11 mm relief cut for the **back** connector, so #5218 is the part. Both drive motors are #5218. There is no left/right variant, and any drawing or document showing #5218 on one side and #5219 on the other is wrong. |
| Motor driver | TB6612FNG dual H-bridge breakout | 1 | $7 | SparkFun ROB-14451 or equiv. 3.3 V logic; VM from 2S pack. STBY → Pi-M GPIO (defaults off). |
| Treads | Printed TPU tank treads, Shore 90A | 2 | (filament) | Closed loop, 28 mm wide, 3.5 mm band, 364.42 mm inner path. **Centre-guide lug system (Session 04):** 29 lugs on the inner face at 12.566 mm pitch — the sprocket's own tooth pitch, so engagement accumulates no error around the loop — 3 mm tall, 8 mm at the tip flaring 45° to 14 mm at the root. Prints as a 28 mm-tall wall, loop plane on the bed, so the extrusions run along the tension path and the lug flare self-supports. **Printed as a circle, not in its running shape (2026-08-26):** r 58.0 mm inner, 123 mm across. A printed part is stress-free in the shape it was printed, so the print shape sets the curvature each element of the band is relaxed at, and every element travels the whole loop — flat on the two runs, 1/20 mm⁻¹ round a wheel. Built oval, an element is born at one extreme and swings the full 0.0500 mm⁻¹; built round, every element is born at 1/58 and the worst swing is 0.0328, taking outer-fibre bending strain through a tread rib from 8.75 % to 5.73 %. Mean curvature is pinned at 2π/path for any closed curve, so the circle is the best available shape and its radius is not a free choice. All 29 lugs and 24 chevrons keep their pitch, because offsetting a closed convex curve outward adds the same length whatever its shape. Secondary benefit: a ring is far less prone to warping or toppling on the bed than two 119 mm straight runs of thin tall wall. One per plate at 123 mm; the oval fitted two. **Herringbone treads (Session 04):** 24 chevrons on the ground face, 1.5 mm deep, 3.5 mm ribs at 25° from transverse, 15.7 mm pitch — 7.6 chevrons under the ground run at any moment. Each arm is built as five short pieces following the path, not one straight bar, so nothing floats clear of the band on the wrapped sections. Relieved *out of* the 3.5 mm envelope rather than added on top, so the tip radius, ride height and ground speed are unchanged and the continuous band becomes 2.0 mm — which nearly halves the outer-fibre bending strain around the 20 mm sprocket radius, helping flex-fatigue life rather than hurting it. Measured 36 g each, down from 50 g smooth. |
| Sprockets / idlers / road wheels | Printed PLA/PETG | 2 + 2 + 4 | (filament) | Sprocket ø40 pitch with 10 lug pockets and a stepped ø6 hub (~25 g); idler ø40 on the tensioning rod (~22 g); road wheels ø24 on a lowered 15.5 mm axle line (~11 g). All on hub-and-spoke lightening, all support-free with the axis vertical. Plus 2 idler tensioner carriers and 6 axle collars. |
| Bearings | 623ZZ (3×10×4) for idlers/road wheels | 8 | $5 | Generic. Two per idler wheel hub + one per road wheel; the wheels carry the bearings, the tub walls only locate the 3 mm shafts. |
| Axle rod | ø3 mm ground steel, 176 mm | 3 | $4 | Added Session 04. One idler rod plus two road-wheel rods. Each runs the full width from one wheel's outer face to the other's, so it cannot cock; the wheels are held axially by the track's lug row and the rod by a printed collar inboard of each wall. Sold as 1 m stock. |
| Drive hub bearings | MR106ZZ (6×10×3) | 2 | $4 | Added Session 03. Pressed into the rear wall from outside; the sprocket rides a stepped ø6 hub set-screwed to the motor shaft. Keeps the wheel load off the N20 gearbox bushings, which a sprocket mounted directly on the output shaft would not — and the 9 mm shaft cannot reach the track centreline at 75 mm anyway. |
| Rear anti-tip tail | Fixed boom + ø25 roller floating 4 mm clear, 90 mm trail | 1 | $0 | **Revised Session 04.** Was a swiveling sprung caster; that design never assembled (pivot bosses and arm eye on mismatched axes) and riding the ground would have scrubbed on every tank turn and lifted weight off the tracks. The tip margin comes from where the roller sits, not from it being sprung, so the tail is now a fixed level boom bolted to the tub rear wall with the roller held clear of the floor — it engages at about 2° of rearward pitch and gives the same 33°→54° margin. Three printed parts, no spring, no pivot, ~26 g. The roller is a PLA hub inside a TPU 90A tyre (same filament as the tracks, so no new BOM line): a bare plastic stop skitters on a hard floor instead of catching, and the tyre is what touches. |

## 2. Arms & Head Servos

| Part | Spec | Qty | Est. cost | Supplier / notes |
|---|---|---|---|---|
| Serial bus servo | Feetech SCS0009 (6V, 2.3 kg·cm stall, 0.75 kg·cm rated, 1 Mbps) | 6 | $66 | L shoulder, R shoulder, head yaw, head nod, shoulder utility-box tilt, brow-blade roll. Chain on one bus. (5th = head nod, 6th = articulated brow; both added Session 02, mass-budget approved.) |
| Bus adapter | Waveshare Bus Servo Adapter (A) — SC/ST half-duplex UART | 1 | $8 | WS-25514. Pi-M UART ↔ bus; reads angle/load/voltage. Fed from 6V servo rail. |

Arm design budget: ≤50 g and ≤90 mm effective lever per arm (keeps shoulder load within rated torque). Utility box mounts to torso shoulder structure (own servo, does not load arm servos). Bus reserves IDs for future elbow servos. STS3215 (19.5 kg·cm, native 7.4 V) documented as upgrade lever if arms lack authority — costs ~+140 g against the weight ceiling.

## 3. Sensing

| Part | Spec | Qty | Est. cost | Supplier / notes |
|---|---|---|---|---|
| ToF distance | VL53L1X carrier, 400 cm, regulated + level-shifted | 1 | $13 | Pololu #3415. I²C 0x29. XSHUT → Pi-M GPIO. |
| IMU | MPU-6050 (GY-521) | 1 | $4 | I²C 0x68. 3.3 V. Mounted on the carrier breadboard below rather than screwed to the shelf directly. |
| IMU carrier | Solderable mini breadboard, 38.1 × 50.8 mm, mount holes 31.8 × 44.5 mm | 1 | $3 | Added 2026-08-26. The IMU, its pull-ups and its connectors solder up as one piece that can be tested off the robot and then dropped onto the Pi-M shelf on four 5 mm standoffs. Cost the shelf plate 24 mm of length (111 → 135 mm, +3 g net of the narrowed tail) and the budget ~8 g of FR-4. |

## 4. Audio (all on Pi-V)

| Part | Spec | Qty | Est. cost | Supplier / notes |
|---|---|---|---|---|
| Microphone | INMP441 I²S MEMS mic | 1 | $5 | 3.3 V. L/R → GND. |
| Amplifier | MAX98357A I²S class-D | 1 | $6 | 5 V. SD_MODE sets gain/channel. |
| Speaker | 8 Ω, 3 W | 1 | $4 | Placed away from mic. |

Integration dependency (Phase 01): mic + amp share the I²S bus; stock `max98357a` / `googlevoicehat` overlays conflict — a **custom combined `simple-audio-card` overlay** is required (one CPU DAI, two codec DAIs). Half-duplex turn-taking; mic gated during playback (Phase 04). No AEC in V1.

## 5. Expressive LEDs & Light

| Part | Spec | Qty | Est. cost | Supplier / notes |
|---|---|---|---|---|
| Mouth array | WS2812B 8-pixel stick | 1 | $5 | **Pi-V**, SPI (GPIO10). Center-out animation during speech. |
| Eye pixels | WS2812B single | 2 | $2 | **Pi-M**. Expression + status color. Diffuser behind each. |
| Battery gauge | WS2812B 5-pixel strip | 1 | $3 | **Pi-M**. Green→yellow→red by charge. |
| Navigation light | 1 W neutral-white LED + lens | 1 | $3 | **Pi-V**, GPIO13 PWM via MOSFET. Camera aid in dim rooms. |
| MOSFET | Logic-level N-ch (nav light) | 1 | $1 | e.g., AO3400 module. |
| Level shifter | 74AHCT125 (3.3→5 V WS2812B data) | 2 | $2 | One per data line (Pi-M chain, Pi-V mouth). |
| Battery-sense ADC | ADS1115 16-bit I²C ADC + divider | 1 | $5 | **Pi-M** I²C 0x48. Drives gauge, low-voltage cutoff, telemetry. |

Pi-M LED groups (eyes + gauge + status) chain on one SPI data line. WS2812B on SPI, not PWM, because PWM channels are taken by the motors.

## 6. Power

| Part | Spec | Qty | Est. cost | Supplier / notes |
|---|---|---|---|---|
| Battery | 2S LiPo 2200 mAh, ≥10C, XT60 | 1 | $18 | ~7.4 V nom / 8.4 V full. ~60–90 min runtime. ~130 g. |
| Buck converter | Adjustable synchronous, 5 A | 2 | $16 | One set 5.0 V (compute), one set 6.0 V (servos). |
| Master switch | SPST toggle/rocker, ≥10 A | 1 | $3 | Main positive, after fuse. |
| Fuse + holder | Inline blade, 7.5 A | 1 | $3 | LiPo short/overcurrent protection. |
| Connectors / wire | XT60 pair, silicone 18–20 AWG | — | $6 | |
| Capacitor bank | 1000 µF 16 V electrolytic ×3, 0.1 µF 50 V ceramic ×5 | 8 | $5 | Electrolytics: 5 V pad, TB6612 VM, servo adapter input. Ceramics: across motor VM, at the MAX98357A, at each 74AHCT125 VCC, and across the sense-divider lower leg. Star ground. |
| Resistor kit | 100 kΩ ×2 (TB6612 STBY pull-down, sense-divider upper leg), 47 kΩ ×1 (sense-divider lower leg), 330 Ω ×2 (WS2812B data series), 1/4 W 1 % metal film | 5 | $3 | Added 2026-08-25 with the power harness schematic; every value is called out in `docs/HARDWARE_power_harness.md`. |
| Distribution board | Perfboard / PDB | 1 | $3 | |
| Balance charger | 2S LiPo balance charger | 1 | $25 | Off-board accessory. Skip if owned. |

Servos **must** be regulated (6 V) — 8.4 V full-charge exceeds the SCS0009 7.4 V max. Motors are 12 V-rated, so battery-direct is safe and keeps motor transients off the compute rail.

## 7. Compute & Mechanical (mostly owned)

| Part | Spec | Qty | Est. cost | Supplier / notes |
|---|---|---|---|---|
| SBC | Raspberry Pi Zero 2 W | 2 | owned | Pi-M (motion), Pi-V (vision). |
| microSD | — | 2 | owned | |
| Camera | 8 MP 1080p CSI | 1 (2 owned) | owned | On Pi-V head; one spare. |
| Filament — PLA | Shell prototyping | — | ~$20 | Likely owned. |
| Filament — PETG | Stress-bearing parts | — | ~$25 | |
| Filament — TPU | Treads, Shore 90A | — | ~$25 | Polymaker PolyFlex TPU90, NinjaTek Cheetah (95A) or Armadillo as firmer fallback. Dry before printing; enable pressure advance. |
| Fasteners | M2/M3 screws, heat-set inserts | — | $15 | |

Chassis lightening is blind pockets only — the tub floor carries no windows, so the only openings in the underside are the two the motor pockets unavoidably make.

**Estimated new-spend total: ~$350–390** (excl. owned items, incl. balance charger; includes 5th + 6th servos and rear trailing caster). Raised from ~$330–370 on 2026-08-25: +$19 correcting the drive motors to $32.45 each (O6) and +$3 for the resistor kit the power harness needs. The 6-pin JST SH motor cables are supplied with the motors and are deliberately not a line item.

---

## GPIO Pin Map — Pi-M (Motion)

40-pin header, 3.3 V logic.

| Function | GPIO (BCM) | Notes |
|---|---|---|
| I²C1 SDA / SCL | 2 / 3 | VL53L1X 0x29, MPU-6050 0x68, ADS1115 0x48 |
| Servo bus UART TXD / RXD | 14 / 15 | → Bus Servo Adapter (A) |
| Motor PWMA / PWMB | 12 / 13 | Hardware PWM0 / PWM1 |
| Motor AIN1 / AIN2 | 5 / 6 | Motor 1 direction |
| Motor BIN1 / BIN2 | 16 / 26 | Motor 2 direction |
| Motor STBY | 20 | Pull-down → motors off on boot/crash |
| Encoder M1 A / B | 17 / 27 | Quadrature |
| Encoder M2 A / B | 22 / 23 | Quadrature |
| VL53L1X XSHUT / INT | 24 / 25 | Reset control / optional interrupt |
| WS2812B chain (eyes+gauge+status) | 10 | SPI0 MOSI, via level shifter |

## GPIO Pin Map — Pi-V (Vision)

40-pin header, 3.3 V logic.

| Function | GPIO (BCM) | Notes |
|---|---|---|
| CSI camera | (ribbon) | Not GPIO |
| I²S BCLK / LRCLK | 18 / 19 | PCM clock / frame-sync (shared) |
| I²S DIN (mic SD) | 20 | INMP441 → Pi |
| I²S DOUT (amp DIN) | 21 | Pi → MAX98357A |
| WS2812B mouth array | 10 | SPI0 MOSI, via level shifter |
| Navigation light | 13 | Hardware PWM → MOSFET gate |

Inter-Pi messaging runs over the WiFi LAN (message queue, protocol finalized Phase 01); no GPIO cross-link reserved (Pi-M UART is committed to the servo bus). Optional GPIO UART cross-link deferred.

---

## Power Budget

| Load | Rail | Typical | Peak |
|---|---|---|---|
| 2× drive motor | Battery-direct ~7.4 V | 0.4 A | ~2.0 A |
| 2× Pi Zero 2 W | 5 V | 0.4 A | 0.8 A |
| WS2812B LEDs (mouth/eyes/gauge) | 5 V | 0.1 A | 0.5 A |
| Navigation light (1 W) | 5 V | — | 0.3 A |
| MAX98357A amp | 5 V | 0.1 A | 1.0 A |
| Sensors (ToF/IMU/ADC) | 3.3 V / 5 V | 0.03 A | 0.05 A |
| 6× SCS0009 servo | 6 V | 0.6 A | ~3.0 A |

Rail sizing: 5 V buck ≥5 A (peak ~2.6 A + headroom); 6 V buck (peak ~3.0 A with 6 servos, within the 5 A buck already specified); motor rail peak ~2 A. Battery-side average ~1.2 A.

---

## Decisions, Levers & Open Items

**Locked this session**

- Path A drive: N20-class 12V/150:1 encoder motors + TB6612FNG, battery-direct on 2S. Accepts ~0.13 m/s and ~1× continuous torque margin in exchange for compact, light, cheap, clean-logic drive.
- 6× SCS0009 on one bus (utility-box tilt + head nod + brow-blade roll). Head is yaw+nod with articulated twin brow blades (offset outboard pivots, one servo driving a pinion → left gear direct, → right gear via an idler so the blades mirror; roll-only, 3 poses). All extra servos share the half-duplex bus (new IDs, no extra GPIO); the 6 V rail at ~3 A stays within the 5 A buck. Arms held light to stay in rated torque.
- All audio consolidated on Pi-V (frees Pi-M I²S pins).
- Custom LED layout: mouth (Pi-V), eyes + battery gauge + status (Pi-M).
- Three-rail power; fuse + STBY interlock + ADS1115 voltage monitoring added for safety.

**Deferred levers (not in V1 spend)**

- Motor-rail boost to ~9–10 V if bench testing shows the drive underpowered.
- STS3215 servo upgrade if arms lack authority.
- 25D-class motors + higher-current driver if Path A proves inadequate (Path B).
- **V2 grasping (tendon gripper):** single-actuator underactuated 3-finger claw with synchronous tendon routing (one winch servo + return spring, à la Yale OpenHand "Model M"). V1 arms built grip-ready — tendon channel up the forearm, claw anchor boss, cable path crossing the shoulder pitch axis, plus a reserved bus ID and a torso winch-servo mount pad — so V2 is a bolt-on, not a redesign. Investigated multiplexing the joints onto one multi-tendon actuator (SIMO clutch banks / SISO time-division); rejected for V1 because independent simultaneous joint motion is needed for Phase 04 and the only one-motor-many-tendon hardware is research-grade. Decided Session 02.
- **Smart-servo standard alt:** Dynamixel XL330-M288 (~18 g, ~5.3 kg·cm, current-based compliant control) if the servo bus is ever re-worked. Different protocol/bus from the Feetech adapter, so not mixable — a clean-sheet swap, not an incremental add.
- **V2 powered waist (body lean):** the signature J5 fore-aft lean at the base-to-torso pivot. Rejected for V1 — needs an STS3215-class servo or a self-locking lead-screw (SCS0009 can't hold the 531 g upper body: ~5.4 kg·cm demanded vs 2.3 kg·cm stall), adds ~116 g pushing worst-case weight to ~1662 g (over the 1.6 kg ceiling), puts the 6 V rail at ~4.5 A near the buck limit, and costs ~+$26, all for only ~7° of decline margin not needed indoors. Its value is expression, not stability. V1 base-to-torso interface built **lean-ready** (reserved pivot-axle bosses + actuator mount pad) so it's a bolt-on, not a redesign. Decided Session 02; rear trailing caster covers the incline/rearward case passively instead.

**Open items**

- ~~Pin exact Pololu motor connector variant~~ — closed Session 03: #5218, back connector.
- ~~Drive motor part number and price contradiction (O6)~~ — closed 2026-08-25 against the Pololu catalogue: **#5218 for both motors, $32.45 each.** The 2026-06-26 entry's $32.45 was the right price attached to the wrong part number. The #5219 was bought deliberately as a fit test and does not fit the chassis cleanly. Three documents were left carrying the stale #5219, all outside that session's scope: `docs/HARDWARE_drive_bringup.md`, `docs/diagrams/bench_full_schematic.svg` and `simulation/chassis/TUNING.md`. All three were corrected 2026-08-25 in session J5-S18 (O12); in `TUNING.md` only the part numbers went, because the same line's left/right channel assignment was measured and is correct.
- ~~Confirm TPU tread + sprocket geometry in FreeCAD~~ — closed Session 04: `build_drivetrain.py` builds all five parts and the guards prove track-to-wheel contact against the real solids.
- ~~Mass ceiling breached (Session 04)~~ — **superseded; the ceiling is not breached.** The 1655 g reading predates the rework that followed it in the same session. `mechanical/preview/mass_budget.py` prints the current figure: **1542 g against the 1.6 kg ceiling**, 58 g of headroom, 1597 g at +25 % on the printed items, under the ceiling in both cases. The figure rose 11 g on 2026-08-26 with `23157ef`, which added the IMU carrier breadboard and grew the Pi-M shelf plate to take it; `ecb244f`, the circular track loop print, revised the same file's track entry the same evening and moved no mass, the loop's 36 g being a function of path length and thickness rather than of the shape it is printed in. The shells went to a 2.0 mm wall rather than the 1.6 mm this entry proposed, and two double-counted lines (the neck riser and the head nod ears) came out. See the Gate Condition Status section below. The identical paragraph was deleted from `phases/PHASE_00_HARDWARE.md` on 2026-08-23 as stale; this copy was missed and is corrected here (O13, session J5-S18).
- **Torso and head STLs contain floating islands (Session 04).** `build_torso.build()` returns 7- and 8-solid compounds and `build_head.build()` 2 and 5; the small ones are keys, pins and bosses that were never fused to their shell, so they slice as islands in mid-air. Neither script has the single-solid guard `build_chassis.py` carries. Both need it before those parts are printed.
- Phase 01: custom `simple-audio-card` overlay for mic + amp coexistence.

---

## Gate Condition Status

**Met 2026-08-21.** Reopened 2026-08-20 for the chassis rework and closed the same week: drivetrain built and guarded, chassis reworked to carry it, every printed part measured from its built solid rather than estimated. Assembled mass 1542 g against the 1.6 kg ceiling — 58 g headroom, +25 % worst case 1597 g, also under; `mechanical/preview/mass_budget.py` is the source, and the figure moves whenever the geometry does. Shell walls went 2.4 -> 2.0 mm on torso and head to get there. Original close text follows.

**Met (2026-06-18).** BOM approved (updated Session 02 to 6× SCS0009 + rear trailing caster). Body baselined in FreeCAD 1.1.1 — all subassembly build scripts run and the full STL set generated and slice-verified. Both Phase 00 gate criteria satisfied.

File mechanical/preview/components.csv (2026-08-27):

item | category | qty | unit_g | option | est | note
# Mass budget line items. option=base is the approved 4-servo build.
# option=nod is the incremental cost of adding a 5th servo for a powered head nod.
# est=1 = printed/estimated mass (soft | +/-20%); est=0 = datasheet/measured (firm).
#
# --- compute / electronics (firm) ---
Pi Zero 2 W | compute | 2 | 11 | base | 0 | board only
microSD card | compute | 2 | 0.5 | base | 0
Camera 8MP + ribbon | compute | 1 | 4 | base | 0
N20 150:1 gearmotor + encoder | drive | 2 | 11 | base | 0 | Pololu micro metal
TB6612FNG breakout | drive | 1 | 3 | base | 0
SCS0009 serial servo | servo | 4 | 20 | base | 0 | L/R shoulder + head yaw + util tilt
Bus servo adapter | servo | 1 | 5 | base | 0 | Waveshare A
VL53L1X carrier | sensor | 1 | 2 | base | 0 | Pololu 3415
MPU-6050 GY-521 | sensor | 1 | 3 | base | 0
IMU carrier breadboard | sensor | 1 | 8 | base | 1 | 38.1 x 50.8 mm solderable mini breadboard; carries the IMU and its connectors as one assembly that can be built up and tested off the robot
ADS1115 ADC | sensor | 1 | 3 | base | 0
INMP441 mic | audio | 1 | 2 | base | 0
MAX98357A amp | audio | 1 | 3 | base | 0
Speaker 8ohm 3W | audio | 1 | 12 | base | 0 | with magnet
WS2812B mouth 8-pixel | led | 1 | 3 | base | 0
WS2812B eye pixel | led | 2 | 1 | base | 0
WS2812B gauge 5-pixel | led | 1 | 2 | base | 0
Nav light LED + lens | led | 1 | 3 | base | 0
Level shifters + MOSFET + small boards | elec | 1 | 5 | base | 0
2S LiPo 2200 mAh | power | 1 | 130 | base | 0
Buck converter 5A | power | 2 | 10 | base | 0 | 5V + 6V rails
Master switch + fuse holder | power | 1 | 10 | base | 0
Wiring harness | wiring | 1 | 50 | base | 1 | whole-robot estimate
Connectors + caps + PDB | power | 1 | 20 | base | 1
Fasteners + heat-set inserts | hardware | 1 | 25 | base | 1 | M2/M3 throughout
#
# --- printed structure (estimated) ---
Chassis tub (PLA) | printed | 1 | 161 | base | 0 | measured; shelf ribs became columns and the deck/floor windows landed
Chassis deck (PLA) | printed | 1 | 32 | base | 0 | measured; lightening windows cut Session 04
Motor retention cap (PLA) | printed | 2 | 6 | base | 0 | measured
Pi-M shelf plate (PLA) | printed | 1 | 23 | base | 1 | computed from the plate solid (18280 mm3 at 1.24 g/cm3); one electronics shelf | Pi forward and the IMU breadboard aft | with wire passthroughs. Grew 111 -> 135 mm for the breadboard's long axis and gave the aft tail back 8.5 mm a side to clear the motor caps. The same computation gives 19.6 g for the 111 mm plate that measured 20
Drive sprocket (PLA) | printed | 2 | 25 | base | 0 | measured; 10-pocket rim on hub and spokes
Idler wheel (PLA) | printed | 2 | 22 | base | 0 | measured
Road wheel (PLA) | printed | 4 | 11 | base | 0 | measured
Idler tensioner carrier (PLA) | printed | 2 | 3 | base | 0 | measured
Axle collar (PLA) | printed | 6 | 1 | base | 0 | measured; two per rod
TPU track loop | printed | 2 | 36 | base | 0 | measured; herringbone treads relieved out of the band drop the continuous section to 2.0 mm. Printed as a 123 mm circle rather than in its running shape from 2026-08-26; the solid computes 35.5 g | unchanged by the form since band area depends only on path length and thickness
Axle rod 3 mm steel | hardware | 3 | 7 | base | 0 | 176 mm each: idler + 2 road wheel. Never budgeted before
Bearings 623ZZ + MR106ZZ | hardware | 1 | 17 | base | 0 | 8 x 623ZZ + 2 x MR106ZZ. Never budgeted before
Misc brackets / mounts (PLA) | printed | 1 | 20 | base | 1 | sensor mounts and board standoffs; caps and shelf now itemised
Torso front+back shell (PLA) | printed | 1 | 218 | base | 0 | measured at a 2.0 mm wall | incl. the new shoulder deck | split pads and deck-bolt ribs
Head shell face+back (PLA) | printed | 1 | 181 | base | 0 | measured at a 2.0 mm wall | incl. split pads; antenna rod is 0.3 g and folded in
Arm assembly (PLA) | printed | 2 | 23 | base | 0 | measured; well inside the 50 g/arm ceiling
Utility box + bracket (PLA) | printed | 1 | 25 | base | 1
#
# --- 5th-servo head-nod option (incremental) ---
SCS0009 serial servo (head nod) | servo | 1 | 20 | nod | 0 | 5th servo
Head nod bracket (PLA) | printed | 1 | 18 | nod | 1 | neck-side bracket only; the head ears are 7.1 g and already inside the measured head shell
Neck reinforcement (PLA) | printed | 1 | 12 | nod | 1 | added structure for nod load
Nod wiring + fasteners | wiring | 1 | 8 | nod | 1
#
# --- articulated brow option (6th servo | Session 02) ---
SCS0009 serial servo (brow roll) | servo | 1 | 20 | brow | 0 | 6th servo
Brow blade (PLA thin) | printed | 2 | 4 | brow | 0 | measured
Brow rocker + gear bridge + idler (PLA) | printed | 1 | 8 | brow | 1 | pinion + left gear + idler + right gear
Brow wiring | wiring | 1 | 4 | brow | 1
#
# --- rear trailing caster (passive stability | approved Session 02) ---
Anti-tip tail boom (PLA) | printed | 1 | 20 | wheel | 0 | measured; fixed boom replacing the sprung caster arm
Anti-tip roller hub (PLA) | printed | 1 | 4 | wheel | 0 | measured; carries the bore and the tyre lips
Anti-tip roller tyre (TPU) | printed | 1 | 2 | wheel | 0 | measured; same 90A filament as the tracks | no new BOM line

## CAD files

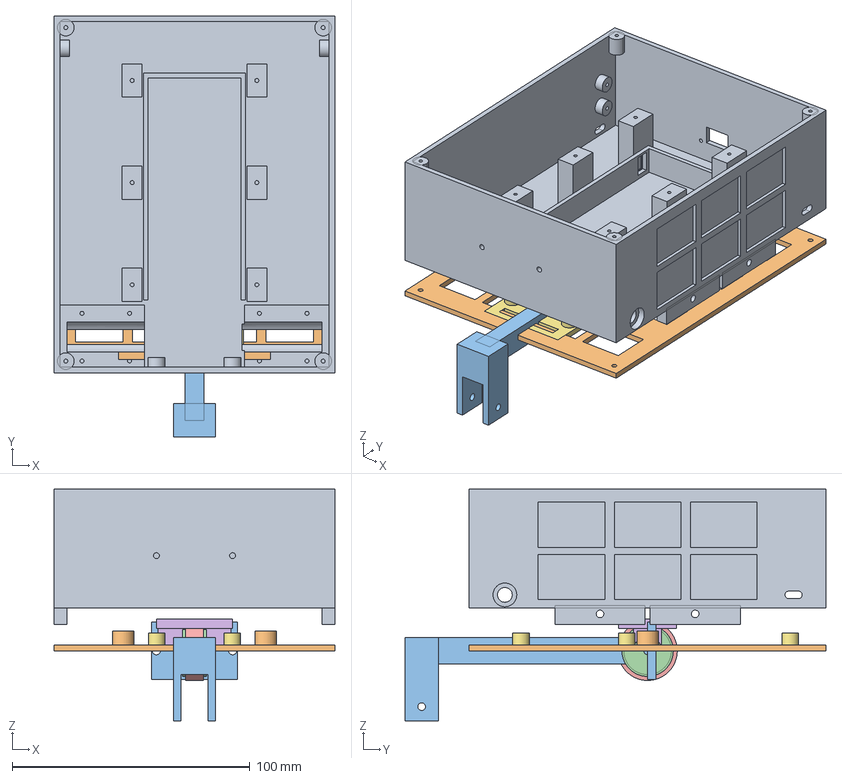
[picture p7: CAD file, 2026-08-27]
mechanical/freecad/chassis_assembly_v1.FCStd
118.0 x 177.0 x 97.5 mm
chassis_tub
chassis_deck
tail_boom
tail_roller
tail_tyre
motor_cap
pi_shelf

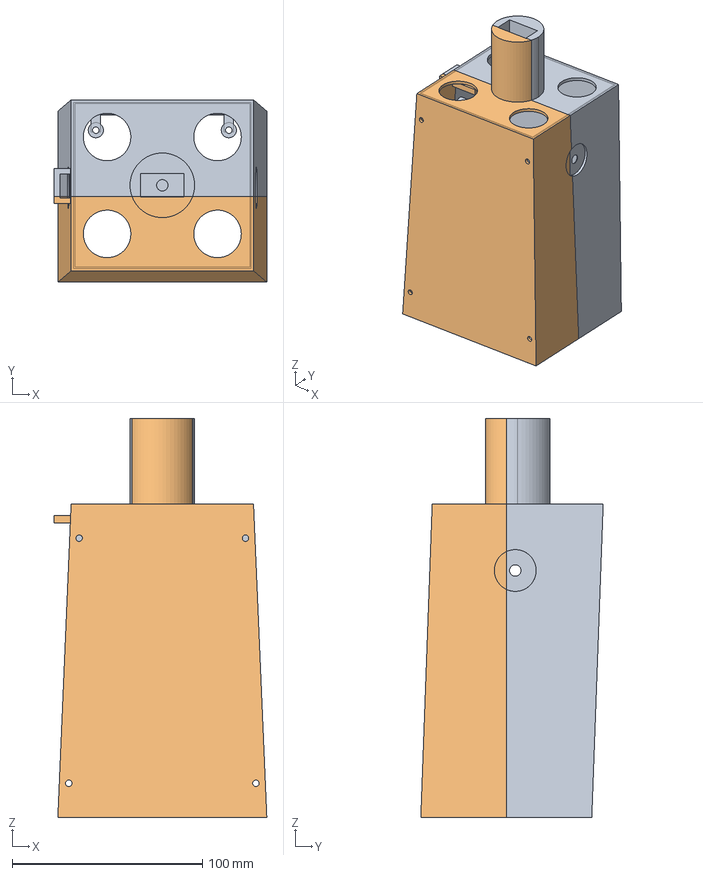
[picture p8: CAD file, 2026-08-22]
mechanical/freecad/torso_assembly_v1.FCStd
111.9 x 96.0 x 210.0 mm
torso_front
torso_back

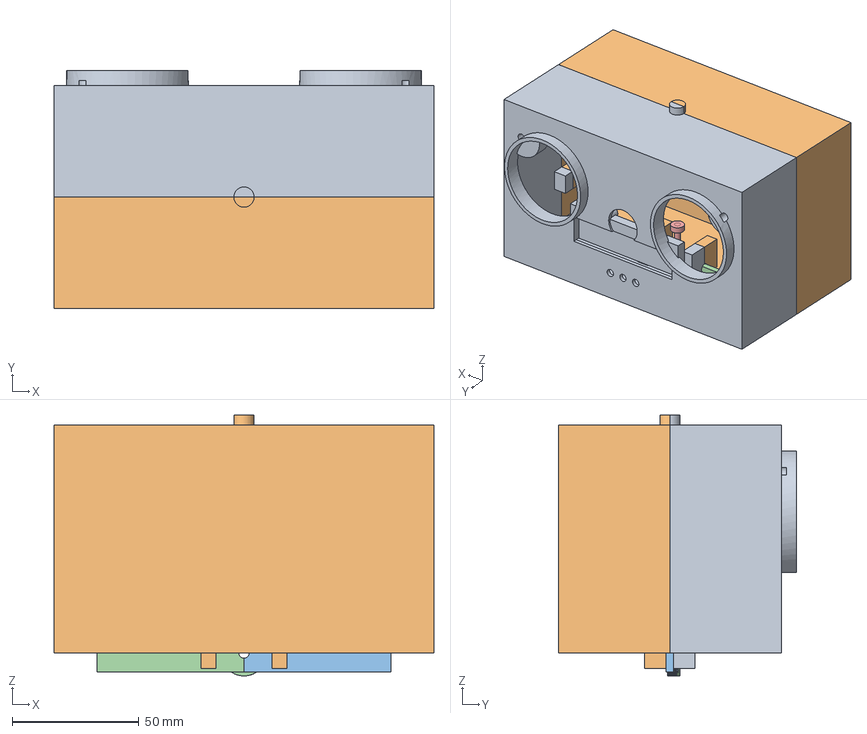
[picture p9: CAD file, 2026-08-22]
mechanical/freecad/head_assembly_v1.FCStd
150.0 x 94.0 x 103.0 mm
head_face
head_back
brow_blade_left
brow_blade_right
antenna

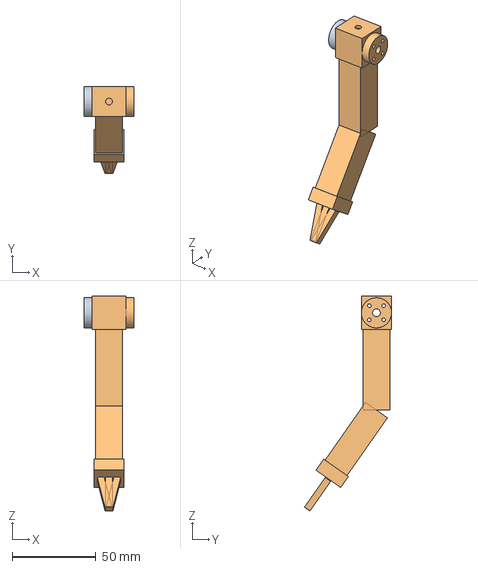
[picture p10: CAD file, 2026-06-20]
mechanical/freecad/arm_assembly_v1.FCStd
30.0 x 51.9 x 128.1 mm
arm_right
arm_left

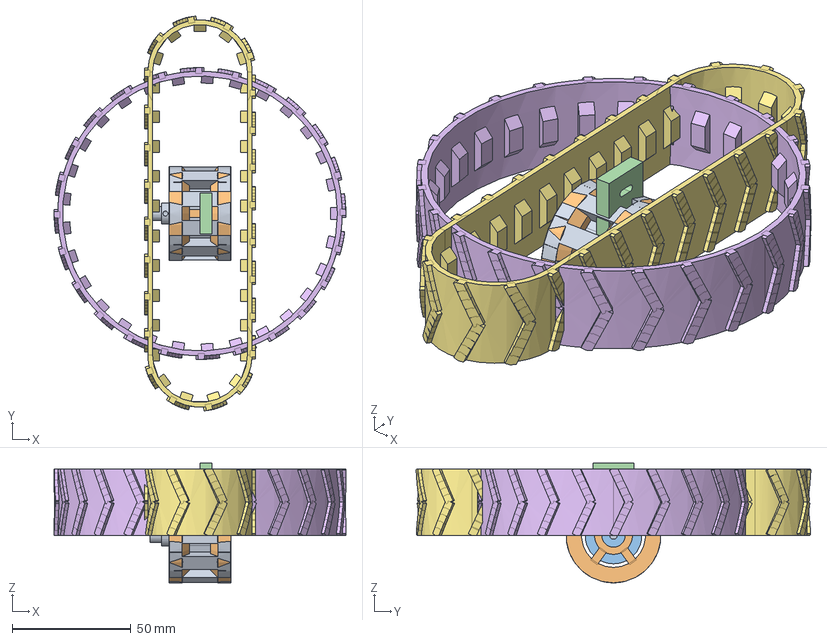
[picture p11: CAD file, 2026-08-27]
mechanical/freecad/drivetrain_v1.FCStd
123.1 x 166.6 x 50.5 mm
drive_sprocket
front_idler
road_wheel
idler_carrier
axle_collar
track_loop
track_loop_running

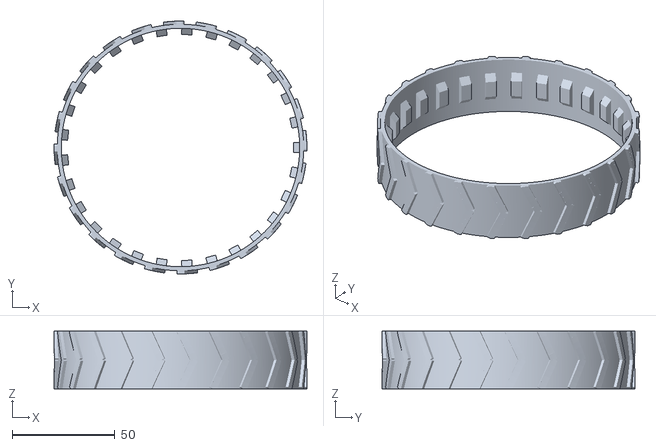
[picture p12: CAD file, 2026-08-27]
mechanical/stl/track_loop_v1.stl
123.1 x 123.1 x 28.0

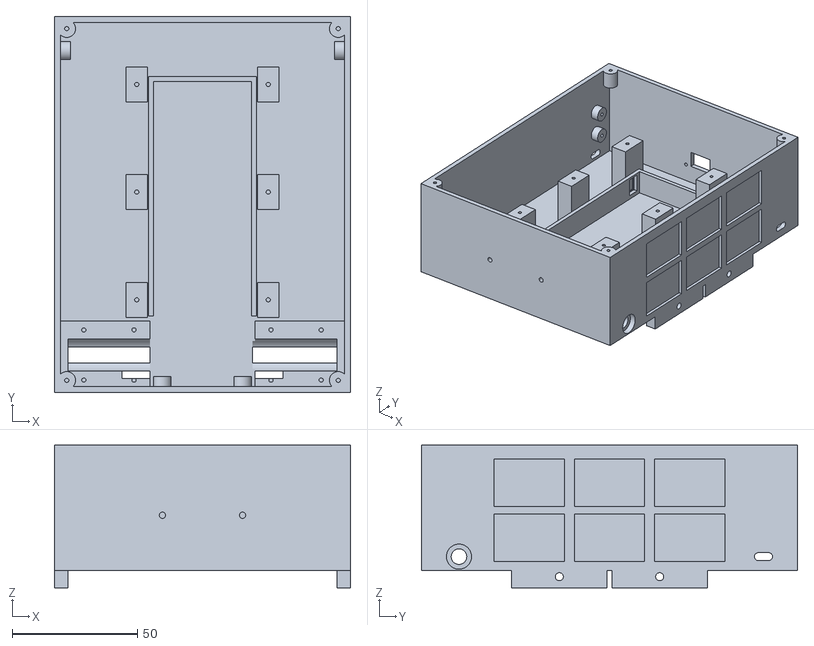
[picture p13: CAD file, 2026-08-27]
mechanical/stl/chassis_tub_v1.stl
118.0 x 150.0 x 57.0

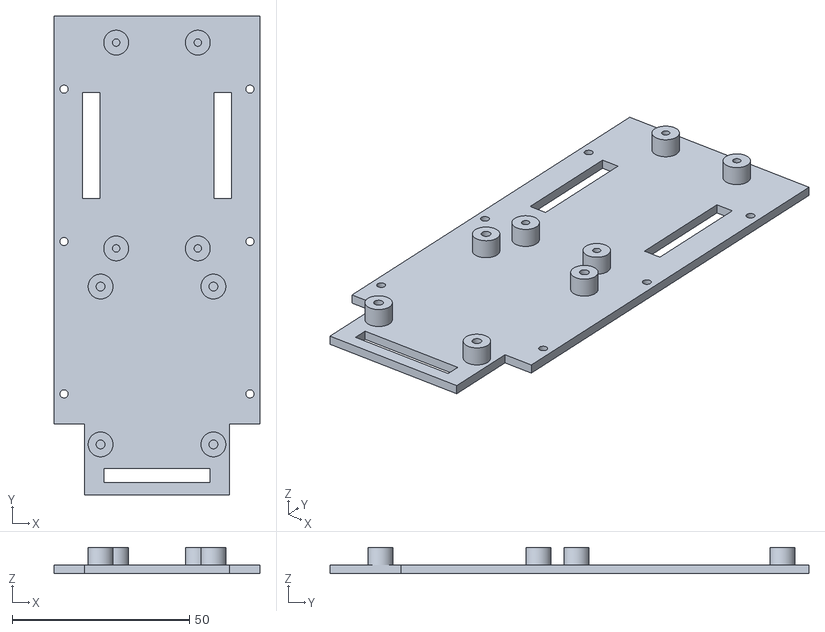
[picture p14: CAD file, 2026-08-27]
mechanical/stl/pi_shelf_v1.stl
58.0 x 135.0 x 7.40

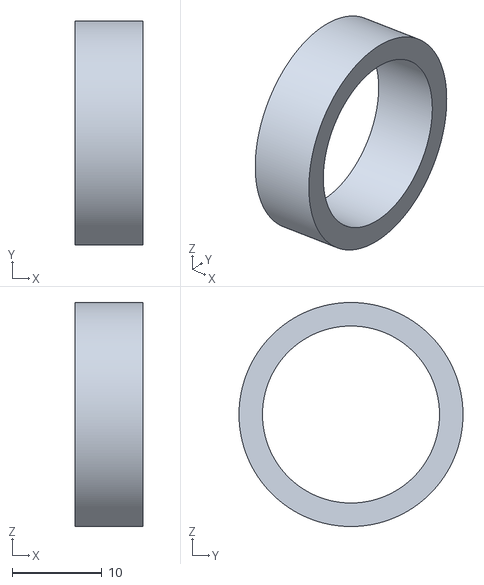
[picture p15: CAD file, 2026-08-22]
mechanical/stl/tail_tyre_v1.stl
7.60 x 25.0 x 25.0

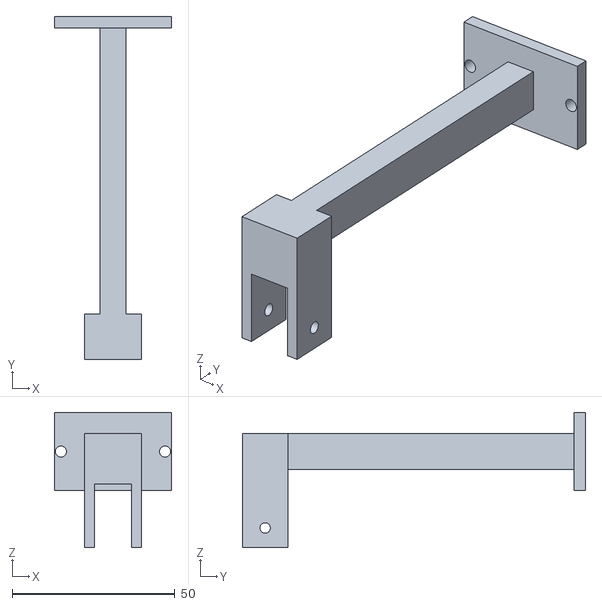
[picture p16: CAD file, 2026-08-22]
mechanical/stl/tail_boom_v1.stl
36.0 x 105.5 x 41.5

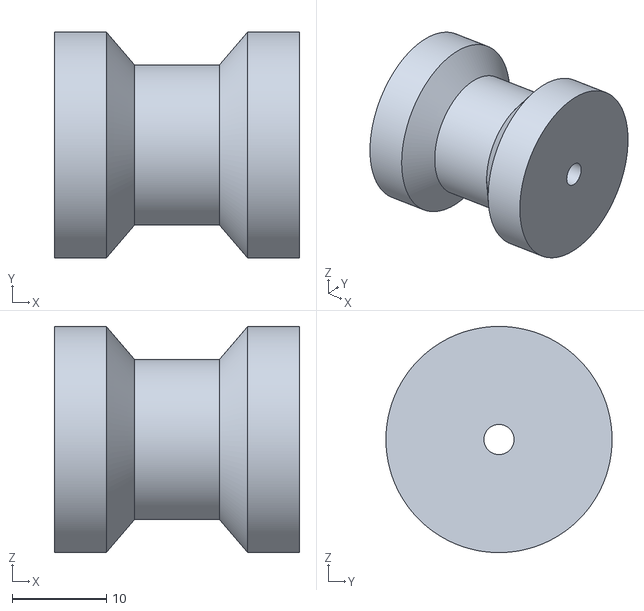
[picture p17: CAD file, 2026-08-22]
mechanical/stl/road_wheel_v1.stl
26.0 x 24.0 x 24.0

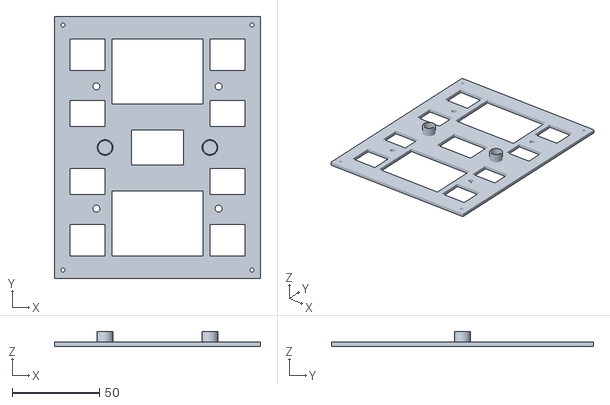
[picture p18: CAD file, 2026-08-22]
mechanical/stl/chassis_deck_v1.stl
118.0 x 150.0 x 8.40

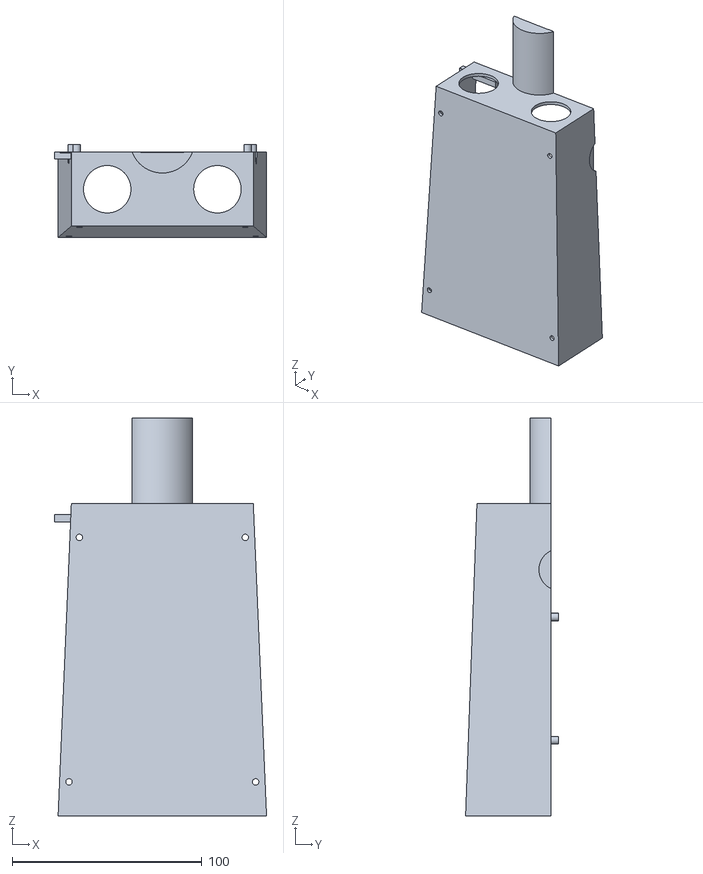
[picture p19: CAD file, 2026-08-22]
mechanical/stl/torso_back_v1.stl
111.9 x 49.0 x 210.0

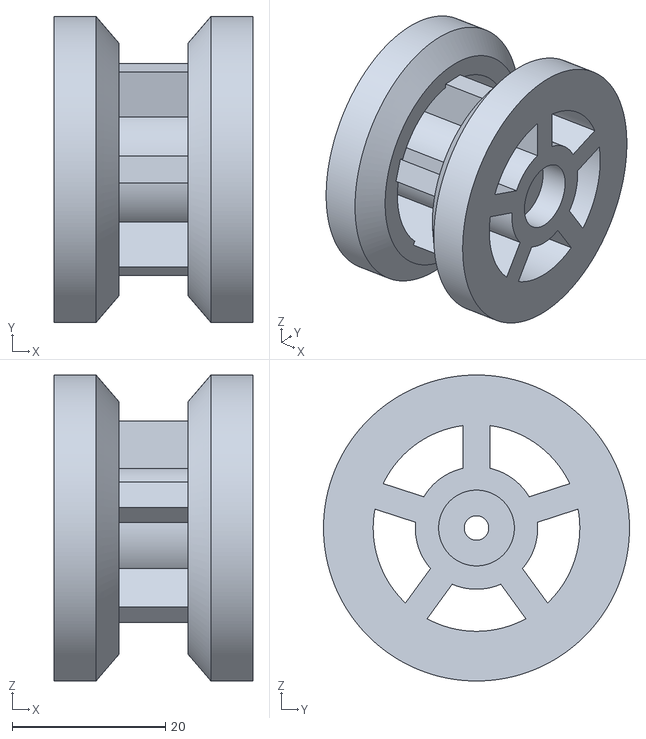
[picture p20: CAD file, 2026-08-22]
mechanical/stl/front_idler_v1.stl
26.0 x 40.0 x 40.0

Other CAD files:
mechanical/stl/drive_sprocket_v1.stl
mechanical/stl/head_back_v1.stl
mechanical/stl/axle_collar_v1.stl
mechanical/stl/tail_roller_v1.stl
mechanical/stl/antenna_v1.stl
mechanical/stl/arm_left_v1.stl
mechanical/stl/arm_right_v1.stl
mechanical/stl/brow_blade_left_v1.stl
mechanical/stl/brow_blade_right_v1.stl
mechanical/stl/head_face_v1.stl
mechanical/stl/idler_carrier_v1.stl
mechanical/stl/motor_cap_v1.stl
mechanical/stl/torso_front_v1.stl

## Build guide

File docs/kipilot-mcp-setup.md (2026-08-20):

# KiPilot MCP Setup — KiCad 10.0.5 Live Control from Claude Desktop

Same integration pattern as the FreeCAD MCP: a local MCP server bridges Claude Desktop to a running KiCad session on `drewsdesktop`. Project: [belaszalontai/kipilot-mcp](https://github.com/belaszalontai/kipilot-mcp) — targets KiCad 10.x, documented for 10.0.1+, so it covers the installed 10.0.5.

**Status note:** early/experimental (v0.1.x on the KiCad forum as of this writing). Read-heavy operations are considered solid; write/mutation is present but should be treated as unproven until tested on a throwaway board.

**Why this doc exists instead of Claude doing the edit directly:** the Filesystem MCP bridge tool errored this session on every call (`invalid outputSchema... unsupported dialect`) — a connector-side bug, not a permissions issue. That tool is what a previous session used to edit `claude_desktop_config.json` directly for the FreeCAD MCP. Until it's working again, the config edit below is manual.

---

## 1. Download and extract

Get the latest Windows build from the [releases page](https://github.com/belaszalontai/kipilot-mcp/releases/latest) — asset name follows the pattern `kipilot-mcp-<version>-windows-x64.zip`. It bundles its own Python runtime, so no local Python install is required.

Extract to a stable, permanent location, e.g. `C:\Tools\kipilot-mcp\`. Don't extract into a temp folder or anywhere that might get cleaned up — the `.exe` path goes straight into Claude Desktop's config.

## 2. Enable KiCad's IPC API

The IPC API is disabled by default in KiCad 10. It's a per-install preference, not per-project:

1. Open KiCad 10.0.5 and the PCB Editor for a project.
2. Go to **Preferences** and look for a **Plugins** section with an "Enable KiCad API" (or similarly worded) checkbox.

I could not independently verify the exact menu wording from official KiCad docs — sources describe it inconsistently and the setting may have moved between 10.0.0 and 10.0.5. If it's not directly under Preferences → Plugins, search KiCad's Preferences dialog for "API." KiCad needs to stay running with a project open while KiPilot connects; it communicates over a local named pipe (Windows) that KiCad exposes once the API is enabled — no manual socket path or API token setup should be needed.

## 3. Add KiPilot to Claude Desktop's config

Real config path (this is an MSIX/Windows Store install, not the generic `%APPDATA%\Claude\` path — see the msix-config note if you need the background):

```
C:\Users\apsus\AppData\Local\Packages\Claude_pzs8sxrjxfjjc\LocalCache\Roaming\Claude\claude_desktop_config.json
```

Easiest route: Claude Desktop → **Settings → Developer → Edit Config**. That opens the real file in your default text editor, which avoids the PowerShell BOM issue entirely.

Add this entry under the existing top-level `mcpServers` key (the FreeCAD entry should already be there — merge, don't replace the file):

```json
"kipilot-mcp": {
  "type": "stdio",
  "command": "C:\\Tools\\kipilot-mcp-<version>-windows-x64\\kipilot-mcp.exe",
  "env": {
    "KIPILOT_KICAD_CLIENT_NAME": "kipilot-mcp",
    "KIPILOT_KICAD_TIMEOUT_MS": "60000",
    "KIPILOT_LOG_LEVEL": "INFO",
    "KIPILOT_LOG_FILE": ".logs/kipilot-mcp.log"
  }
}
```

Replace `<version>` with the actual extracted folder name. Write access is off by default — KiPilot starts read-only. To allow it to move footprints, edit tracks, etc., add:

```json
"KIPILOT_ENABLE_MUTATIONS": "1"
```

to the `env` block once you've verified the read-only connection works and want to test edits (start on a throwaway board given the project's experimental status).

If you script the edit instead of using Edit Config, use no-BOM UTF-8 (`New-Object System.Text.UTF8Encoding($false)` in PowerShell) and back up the file first — a BOM-corrupted config breaks the whole app's settings load, not just MCP.

## 4. Restart and verify

Fully quit and reopen Claude Desktop (tray icon → Quit, not just closing the window — standard for picking up MCP config changes). In a chat, ask it to run the KiPilot tool `ping_kicad` to confirm the connection before attempting any board operations.

---

## Open items for next session

- Confirm exact KiCad 10.0.5 menu path for enabling the IPC API once you've found it — worth a one-line memory update so the next KiCad-MCP task doesn't re-derive it.
- Re-test the Filesystem MCP bridge; if it's working again, future config edits (this one or others) can be done directly from a Cowork session instead of handed off.
- Once `ping_kicad` succeeds, decide whether to flip on `KIPILOT_ENABLE_MUTATIONS` for actual PCB editing work, or keep KiPilot read-only for design review/inspection only.

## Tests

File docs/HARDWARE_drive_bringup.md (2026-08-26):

# Drive Electronics Bringup — TB6612FNG + N20 Encoder Motors (Pi-M)

Reference for Phase 02 Task 1 (`MotorDriver`) wiring and bench bringup. Pairs with
the `BOM.md` GPIO pin map and power budget. Goal: bring up the two drive motors on
the bench (wheels free, **not** on the chassis/treads) with correct direction,
speed, braking, encoder feedback, and a fail-safe standby interlock.

## Hardware

| Part | Detail |
|---|---|
| Drive motor ×2 | Pololu #5218 — 150:1 Micro Metal Gearmotor HPCB 12V, 12 CPR encoder, back connector |
| Driver | Pololu #713 — TB6612FNG dual H-bridge carrier (VM 4.5–13.5 V, VCC 2.7–5.5 V, 1 A cont. / 3 A peak per ch) |
| Motor rail (VM) | Battery-direct 2S LiPo, ~7.4 V nom (8.4 V full) — within TB6612 range; 1000 µF across VM |
| Logic rail (VCC) | 3.3 V from Pi-M (so all logic + encoder outputs are 3.3 V, GPIO-safe) |
| Encoder | 12 CPR on the motor shaft × 150.58 gearbox ≈ **1807 counts / output rev** at 4× quadrature, which is **not** the operative figure: the `gpiozero.RotaryEncoder` decode below is 1×, so `COUNTS_PER_OUTPUT_REV` is **451.74** (450.6 measured at S10; see `simulation/chassis/TUNING.md`) |

## Wiring — Pi-M (BCM) ↔ TB6612FNG ↔ motors

| TB6612 pin | Pi-M GPIO | Notes |
|---|---|---|
| PWMA | GPIO 12 | hardware PWM0 — motor A (left) speed |
| AIN1 | GPIO 5 | motor A direction |
| AIN2 | GPIO 6 | motor A direction |
| PWMB | GPIO 13 | hardware PWM1 — motor B (right) speed |
| BIN1 | GPIO 16 | motor B direction |
| BIN2 | GPIO 26 | motor B direction |
| STBY | GPIO 20 | **pulled LOW on boot → motors OFF**; drive HIGH to enable |
| VCC | 3.3 V | logic |
| VM | battery + (after fuse/switch) | motor supply, ~7.4 V |
| GND | common | star ground: Pi ↔ TB6612 ↔ battery |
| AO1/AO2 | motor A leads | swap if A runs backwards |
| BO1/BO2 | motor B leads | swap if B runs backwards |

| Encoder | Pi-M GPIO | Notes |
|---|---|---|
| M1 A / B | GPIO 17 / 27 | left motor quadrature |
| M2 A / B | GPIO 22 / 23 | right motor quadrature |
| Encoder VCC / GND | 3.3 V / common | keeps A/B outputs at 3.3 V |

## TB6612FNG control contract (per channel; STBY must be HIGH to run)

| IN1 | IN2 | PWM | Result |
|---|---|---|---|
| H | L | duty | **CW / forward** (speed ∝ duty) |
| L | H | duty | **CCW / reverse** (speed ∝ duty) |
| H | H | x | **short brake** (terminals shorted) |
| L | L | x | **stop / coast** (outputs high-Z) |
| x | x | x (STBY=L) | **standby — all outputs off** |

Note: with a direction set, **PWM=0 is a short brake, not a coast**. True coast is
`IN1=L, IN2=L`. This drives the API:

- `set_speed(left, right)` — sign → direction pins, `abs()` → PWM duty (0–1 → 0–100 %).
  `0.0` → coast (`IN1=L, IN2=L`).
- `stop()` — coast both (`IN1=L, IN2=L`), PWM 0.
- `brake()` — short brake both (`IN1=H, IN2=H`); faster stop than coast.
- Enable/disable — STBY HIGH to run; pull LOW on shutdown / offline fallback.

"Forward" = robot drives forward. Confirm each motor's direction on the bench and
record any per-side lead/pin swap (this is the sim's "motor asymmetry" item — log it
in `simulation/chassis/TUNING.md`).

## PWM

Use **hardware PWM** on GPIO 12/13 (PWM0/PWM1) — software PWM jitters and wastes CPU
on the loop. `gpiozero` with the `lgpio` pin factory (installed by
`scripts/setup_motion_pi.sh`) or `pigpio` both give stable hardware PWM. Frequency
~**20 kHz** (above audible, well under the TB6612 100 kHz max).

## Encoders

12 CPR × 150.58:1 ≈ 1807 counts/output-rev at 4× quadrature, which is **not** the operative figure: the `gpiozero.RotaryEncoder` decode below is 1×, so `COUNTS_PER_OUTPUT_REV` is **451.74** (450.6 measured at S10; see `simulation/chassis/TUNING.md`).
Decode quadrature with interrupt/callback counting (`gpiozero.RotaryEncoder` or
`pigpio` edge callbacks) — never poll in the loop. `EncoderReader` publishes signed
left/right tick counts to the motion loop; the sign must match motor "forward". Used
in Phase 02 for closed-loop checks and in Phase 05 for odometry. (Forward velocity
for the policy obs is derived from these — see `TUNING.md`.)

## Bench bringup procedure (`scripts/test_motors.py`)

Motors on the bench, **wheels free, robot not on treads, nothing in the pinch path.**

1. Power logic only (Pi 3.3 V), VM off → confirm STBY reads LOW and outputs are dead.
2. Power VM (fused, 7.4 V). Run the timed sequence: forward 2 s → stop 0.5 s →
   backward 2 s → stop 0.5 s → turn left 1 s → turn right 1 s.
3. Verify per motor: correct direction each phase, speed scales with duty, encoder
   counts increment with the correct sign, coast vs brake behave differently.
4. Verify the STBY interlock: with STBY LOW, `set_speed` does nothing.
5. Sanity-check current: ~0.4 A/motor running, ~2 A stall (BOM); watch for hot driver.

## Safety

- Inline fuse (7.5 A, BOM) on VM; master switch after fuse.
- TB6612 has reverse-protection on **VM only**, not VCC — double-check VCC polarity.
- STBY LOW on boot/crash is the primary fail-safe; `MotorDriver` and the offline
  fallback must both drive treads to stop (coast or brake) and can pull STBY LOW.
- Keep fingers clear of sprockets/treads; bench-test before chassis assembly.

## Task 1 success criteria

`set_speed` / `stop` / `brake` produce correct directions on both motors; PWM duty
scales speed; encoders count with correct sign; STBY interlock holds motors off until
enabled; `scripts/test_motors.py` runs the sequence cleanly on the bench.

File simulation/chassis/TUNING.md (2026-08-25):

# Chassis Sim — Tuning & Sim-vs-Reality Log

Assumptions baked into the simulation that must be confirmed against hardware
during the Phase 02 physical integration test (Task 6). Record measured values
and any sim adjustments here as they are made.

| Quantity | Sim value | Basis | Confirm by | Status |
|---|---|---|---|---|
| Motor stall torque | 0.25 N·m / motor | Pololu 150:1 HPCB ~0.41 N·m @12 V, scaled to 7.4 V | Bench stall test (current × Kt, or lever + scale) | open |
| Motor no-load speed | 12.9 rad/s (~0.30 m/s) | ~200 rpm @12 V scaled to 7.4 V | No-load wheel RPM on the bench | open |
| Ground friction (slide) | 1.0 | Hardwood/tile default | Drive on target floor; compare slip/accel | open |
| Wheel/track friction (slide) | 1.2 | TPU 90A lug estimate | Measure no-slip tractive limit | open |
| Trunk CoM height | 0.110 m | Mass-weighted estimate from components.csv | FreeCAD CoM report or balance test | open |
| Trunk effective inertia height | 0.18 m | Box-proxy modelling constant | Optional: bifilar/measured yaw inertia | open |
| In-place yaw cap | ~0.34 rad/s | Sim measurement, condim=3 skid | Measure real spin rate | open |

## Known sim → reality gaps to watch

- **Motor asymmetry.** Sim treats both sides identically. Real gearmotors differ;
  expect a straight-line drift to correct (bias term or per-side gain in the
  deployment shim, not necessarily a retrain).
- **Track compliance & slip.** Rigid wheels approximate a compliant TPU belt.
  If real turns are easier/harder than sim, adjust `WHEEL_FRICTION` slide and/or
  bump contacts to `condim=4` to add torsional friction.
- **Caster scrub.** The rigid sphere does not swivel; if the real swivelling
  caster changes turn dynamics noticeably, model the trailing arm explicitly.

## Observation reconstruction on Pi-M (Task 5)

The policy consumes a 9-element observation. In sim these come from MuJoCo
ground-truth sensors; on Pi-M each must be reconstructed from real hardware and
fed to `locomotion_v1.onnx` in the **same order and units** (`env.py` `_obs()`
is the authoritative layout).

| Obs channel | Sim source | Pi-M source |
|---|---|---|
| forward velocity | `framelinvel` (body x) | encoder odometry: mean drive-wheel speed × wheel radius |
| lateral velocity | `framelinvel` (body y) | not directly measurable — set ~0 (small during skid turns); candidate sim-to-real gap |
| yaw rate | `gyro` z | MPU-6050 gyro z, directly |
| roll, pitch | `framequat` | MPU-6050 accel+gyro **fusion** (see note) |
| left/right wheel speed | `jointvel` (rear wheels) | quadrature encoders (GPIO 17/27, 22/23), counts → rad/s |
| command (v, w) | episode command | intent from the motion loop (Pi-V → Pi-M) |

**Roll/pitch come from IMU fusion — this is the accelerometer's job.** The
MPU-6050 (BOM §3, I²C 0x68) is a 6-axis IMU: 3-axis accelerometer + 3-axis gyro.
Roll and pitch are obtained by fusing the accelerometer's gravity vector (the
absolute tilt reference) with the gyro's angular rate (drift-free over the short
term); the gyro alone drifts and the accelerometer alone is noisy under
acceleration. Use a complementary filter or the MPU-6050's onboard DMP. **No
separate accelerometer is needed — it is already inside the IMU.**

**No magnetometer → no absolute heading.** The MPU-6050 has no magnetometer, so
yaw is gyro-integrated and drifts. That is fine for Phase 02 because the policy
uses yaw *rate* only, never absolute heading. If a later phase needs
heading-hold or map-relative navigation, upgrade to a 9-axis IMU (ICM-20948 /
MPU-9250).

## Bench bringup results — Task 1 drive integration (2026-07-12)

First power-on of the TB6612 + N20 encoder motors on the bench (wheels free).
Driver, hardware PWM, STBY interlock, coast/brake, and both encoders verified
with `scripts/test_motors.py`. Two per-side corrections, both fixed **in
hardware**, so `MotorDriver`/`EncoderReader` stay at `invert_*=False`:

- **Left motor ran backwards** → swapped its output leads to RED→**AO2**,
  BLK→**AO1** (was RED→AO1/BLK→AO2). This is the "Motor asymmetry" gap above,
  resolved by a lead swap rather than a per-side gain.
- **Right encoder counted backwards on forward** → swapped that motor's encoder
  channels to **YEL→GPIO23, WHT→GPIO22** (A/B were reversed). Left encoder was
  already correct.

Side assignment **locked: LEFT = channel A, RIGHT = channel B.**
Post-fix run: forward → both encoders positive (L +984 / R +980, within ~0.4%),
backward → both negative, CCW → L−/R+, CW → L+/R−. Motors track closely.

- **Encoder counts/output-rev recalibrated (affects the wheel-speed obs
  channels, Task 6).** Measured counts run ~4x below the `1807` (raw 4x-quadrature)
  figure because `gpiozero.RotaryEncoder` decodes full-step (1x): effective
  ~**452 counts/output-rev** (3 cycles/motor-rev × 150.58). `COUNTS_PER_OUTPUT_REV`
  updated 1807 → 451.74 provisionally; confirm empirically with
  `scripts/test_motors.py --calibrate` and set the exact value. If counts are also
  *missed* at speed (callback latency on the single-core Pi Zero 2 W), the
  low-speed calibration won't reveal it — watch obs-vs-commanded speed in Task 6.

## Encoder calibration — Task 6a (2026-08-10)

**Result: 450.6 counts/output-rev measured, left/right spread 0.4%.
`COUNTS_PER_OUTPUT_REV` stays at 451.74.**

The measurement confirms the derived constant rather than replacing it. 451.74
is fixed by integer quantities (3 quadrature cycles/motor-rev × 150.58 gearbox,
both from tooth and pole counts), whereas the measured figure carries
tap-timing noise; the 0.25% gap between them is that noise, not a physical
difference, so adopting 450.6 would trade an exactly-derived value for a
noisier estimate of the same thing. What the measurement does settle is the
question it was designed for: `gpiozero.RotaryEncoder` decodes **1x, not 4x**,
killing the ~1807 candidate. That alternative would have been a factor-of-four
error in both wheel-speed obs channels and in all odometry.

**Method changed — the hand-rotation procedure originally specified for Task 6a
is impossible.** The 150.58:1 N20 gearbox is not backdrivable at the output
shaft: the wheel does not turn by hand, and the force required would split the
gearcase before the shaft moved usefully. This was confirmed mechanical rather
than electrical by detaching the motor from the TB6612 completely and finding
it still locked, ruling out the short-brake state (IN1=H, IN2=H) that floating
pins can leave behind once `MotorDriver.close()` releases them. Note that
`--calibrate` therefore now **runs the motors** — wheels must be free and the
robot off the treads before invoking it.

The replacement is a powered measurement: one wheel at a time at low duty
(`--calib-duty`, default 0.25), tapping Enter at each pass of a mark on the
wheel, with the script least-squares-fitting encoder count against revolution
index over `--revs` passes. The slope is counts/output-rev. Fitting the slope
rather than dividing total counts by revolutions is what makes this usable by
hand: a constant human reaction lag displaces the intercept and leaves the
slope unchanged, so the result depends on the taps being consistent, not fast.

**Carried forward:** this was measured at ~0.25 duty, so the missed-count risk
noted in the Task 1 entry above is still open. Low-speed calibration cannot
reveal counts dropped at speed through callback latency on the single-core Pi
Zero 2 W. Compare observed against commanded wheel speed during Task 6b, where
the robot runs at real drive speeds for the first time.

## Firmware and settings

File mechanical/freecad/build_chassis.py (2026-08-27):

"""Johnny 5 - chassis / tread base build script (Phase 00, Task 7).

Run headless:   freecadcmd build_chassis.py
or paste into the FreeCAD 1.1.1 Python console.

Outputs (relative to repo root):
    mechanical/stl/chassis_tub_v1.stl
    mechanical/stl/chassis_deck_v1.stl
    mechanical/stl/tail_boom_v1.stl
    mechanical/stl/tail_roller_v1.stl
    mechanical/stl/tail_tyre_v1.stl       (TPU 90A)
    mechanical/stl/motor_cap_v1.stl      (print x2 -- one per motor cradle)
    mechanical/freecad/chassis_assembly_v1.FCStd

Coordinate frame: origin at the centre of the track footprint on the ground
plane. +X right, +Y forward, +Z up. Parallel-track stance (confirmed Session 02).

The drivetrain wheels/sprockets/idlers and the TPU track print as separate
parts; this script builds only the structural tub and its top deck, plus every
mounting feature the BOM calls out.
"""

import os
import FreeCAD as App
import Part
from FreeCAD import Vector

import j5_lib as L
import j5_params

P = j5_params.get()

# --- paths ---------------------------------------------------------------
HERE = os.path.dirname(os.path.abspath(__file__))
REPO = os.path.dirname(os.path.dirname(HERE))
STL = os.path.join(REPO, "mechanical", "stl")
os.makedirs(STL, exist_ok=True)

# --- key positions -------------------------------------------------------
W = P["tub_width"]                 # X extent
Lg = P["tub_len"]                  # Y extent (length)
H = P["tub_height"]
WALL = P["tub_wall"]
Z0 = P["ground_clearance"]         # tub floor underside
ZTOP = Z0 + H                      # tub rim
AXLE = P["axle_z"]                 # sprocket / idler axle line
RW_AXLE = P["roadwheel_axle_z"]    # road-wheel axle line, 8 mm lower
Y_IDLER = P["idler_slot_cy"]       # centre of the idler tensioning slot
Y_REAR = -P["wheelbase"] / 2.0     # drive sprocket / motors
Y_FRONT = P["wheelbase"] / 2.0     # idler
X_WALL = W / 2.0                   # side-wall outer face
X_WALL_IN = X_WALL - WALL          # side-wall inner face


def _xhole(sgn, y, z, r, margin=1.0):
    """Through-hole in the side wall on side `sgn`, centred on (y, z).

    L.cyl only ever extrudes +X, so the start point must be the *lower* x of
    the two wall faces whichever side is being cut. The previous signature took
    a raw start point and every caller passed sgn * (X_WALL + n): correct on the
    left, and on the right it started outboard and extruded further outboard,
    cutting nothing. That is why the printed tub came off the bed with no motor
    shaft, road-wheel or idler holes on the right-hand wall.
    """
    x0 = min(sgn * X_WALL, sgn * X_WALL_IN) - margin
    return L.cyl(r, WALL + 2 * margin, x0, y, z, axis="x")


def _wall_hole(sgn, y, z, r, thick, margin=1.0):
    """Through-hole in a wall of local thickness `thick` on side `sgn`.

    `thick` is measured inboard from the wall's outer face, so the same helper
    serves the plain 2.4 mm wall and the thicker skirt pads carrying the
    road-wheel rods.
    """
    x0 = min(sgn * X_WALL, sgn * (X_WALL - thick)) - margin
    return L.cyl(r, thick + 2 * margin, x0, y, z, axis="x")


# --- tub shell -----------------------------------------------------------
def tub():
    s = L.tube_shell(W, Lg, H, WALL, z0=Z0, open_top=True)
    return s


# --- motor cradles (rear, one per side, axis along X) --------------------
def _cradle_dims():
    """Shared cradle geometry, so motor_cap() cannot drift out of step with it.

    Both lengths come from j5_params.derive() rather than being recomputed
    here, because validate.py was deriving its own copy and the two disagreed.

    Width is set by the cap screws: the columns must sit clear of the drop-in
    slot on both sides.
    """
    return P["cradle_l"], P["cradle_w"], AXLE + P["motor_dia"] / 2.0 + 3.0


def _pocket_span(sgn):
    """(inboard, outboard) x of the motor pocket on side `sgn`.

    The outboard end is the motor's front face, which stops drive_boss_t short
    of the wall inner face. That reserved slug is what the drive bearing seat
    shoulders against -- if the bore or the drop-in slot ran all the way to the
    wall there would be nothing behind the bearing to stop it pressing through.
    """
    cradle_l, _, _ = _cradle_dims()
    lo = sgn * (X_WALL_IN - cradle_l)
    hi = sgn * (X_WALL_IN - P["drive_boss_t"])
    return (lo, hi) if sgn > 0 else (hi, lo)


def _cap_dims():
    """Cap footprint, clipped off the cradle footprint.

    The cradle is fused to the tub, so it can run into the side and rear walls
    and simply merge with them. The cap cannot: it is a separate printed part
    that has to drop between those walls, so it gives up motor_cap_wall_clear
    against each one. At the current wheelbase the rear wall is the binding
    constraint, sitting only 12.6 mm behind the motor axis.
    """
    _, cradle_w, _ = _cradle_dims()
    clear = P["motor_cap_wall_clear"]
    rear_span = Lg / 2.0 - WALL - abs(Y_REAR) - clear
    # Sized off the pocket, not the cradle: the cap closes the drop-in slot, and
    # the slot now stops short of the wall to leave the bearing seat its shoulder.
    cap_l = P["motor_pocket_l"] - 2 * clear       # clears the side wall outboard
    cap_w = min(cradle_w, 2.0 * rear_span)        # clears the rear wall
    return cap_l, cap_w


def _rim_boss_xy():
    """Deck screw-boss centres. Shared with deck() so the holes cannot drift apart.

    The inset is set so each boss overlaps the tub wall it sits against by 1 mm.
    At the original W/2-6 the bosses stopped 0.1 mm short of the inner faces and
    came out of the fuse as four solids floating free of the tub.
    """
    inset = P["tub_wall"] + P["boss_od"] / 2.0 - 1.0
    return [(sx * (W / 2.0 - inset), sy * (Lg / 2.0 - inset))
            for sx in (-1, 1) for sy in (-1, 1)]


def motor_cradles():
    solids, cuts = [], []
    fit = P["motor_fit_clear"]
    bore_r = (P["motor_dia"] + fit) / 2.0
    cradle_l, cradle_w, cradle_top = _cradle_dims()
    depth = P["motor_cap_screw_depth"]
    for sgn in (-1, 1):
        # outboard end flush with inner wall face, body reaching inward
        x_out = sgn * X_WALL_IN
        x_in = x_out - sgn * cradle_l
        cx = (x_out + x_in) / 2.0
        # At the current wheelbase the widened block runs 0.9 mm past the rear
        # wall's inner face and merges into it on the fuse. That is intended --
        # it stiffens the wall behind the drive loads -- and it stays inside the
        # tub's outer face, which validate.py checks.
        block = L.box(cradle_l, cradle_w, cradle_top - Z0, cx, Y_REAR, Z0)
        # Bore and drop-in slot both stop at the motor front face rather than
        # running the length of the block, leaving drive_boss_t of solid material
        # behind the bearing seat. Previously the slot was cradle_l - 4, which
        # came out exactly equal to motor_body_len: zero axial clearance, with a
        # 2 mm roof tab at each end for the motor to catch on.
        lo, hi = _pocket_span(sgn)
        pk_l = hi - lo
        pk_cx = (lo + hi) / 2.0
        bore = L.cyl(bore_r, pk_l + 1, lo - 1, Y_REAR, AXLE, axis="x")
        slot = L.box(pk_l, P["motor_dia"] + fit, cradle_top - AXLE + 2,
                     pk_cx, Y_REAR, AXLE)
        # Connector relief. The Pololu #5218 is the back-connector variant, and
        # its connector stands proud of the can toward the tub rear, so the
        # -Y pocket wall is opened over the inboard motor_conn_relief_l -- the
        # travel needed to seat the shaft fully through the sprocket.
        # Full pocket height, which grazes the inboard cap screw on that side;
        # the alternatives all fail elsewhere. Widening the screw spacing to
        # clear it puts the cradle past the tub rear wall, and the cap cannot
        # grow to match because rear_span already pins cap_w at 24.4.
        rl, rd = P["motor_conn_relief_l"], P["motor_conn_relief_d"]
        y_edge = Y_REAR - (P["motor_dia"] + fit) / 2.0
        rz0 = AXLE - bore_r
        rx0 = lo if sgn > 0 else hi - rl
        relief = L.box(rl, rd, (cradle_top + 2) - rz0,
                       rx0 + rl / 2.0, y_edge - rd / 2.0, rz0)
        solids.append(block)
        cuts.append(bore)
        cuts.append(slot)
        cuts.append(relief)
        # four tapped columns per side, flanking the slot, for the retention cap
        for dx in (-P["motor_cap_screw_x"] / 2.0, P["motor_cap_screw_x"] / 2.0):
            for dy in (-P["motor_cap_screw_cc"] / 2.0, P["motor_cap_screw_cc"] / 2.0):
                cuts.append(L.cyl(P["m2_tap_dia"] / 2.0, depth + 1,
                                  pk_cx + dx, Y_REAR + dy, cradle_top - depth))
    return solids, cuts


# --- drive sprocket bearing (rear wall, one per side) --------------------
def drive_axle_features():
    """Rear-wall bearing seat carrying the drive sprocket.

    The sprocket sits on the track centreline, track_cc/2 outboard, which a
    9 mm output shaft cannot reach from a motor whose body cannot pass the
    wall. Extending the shaft would not help either: a sprocket hung 16 mm off
    an N20 output shaft feeds the robot's weight and every tread tension spike
    straight into the gearbox bushings, which are not built to take it.

    The sprocket instead rides a stepped hub, bored 3 mm and set-screwed to the
    motor shaft over its full 9 mm, running in a bearing pressed into the rear
    wall from outside. The wall carries the load; the motor only supplies
    torque. Seat depth is the bearing width, taken from the outer face, so the
    shoulder it presses against is the drive_boss_t slug left by _pocket_span.
    """
    cuts = []
    bw = P["drive_bearing_w"]
    boss_t = P["drive_boss_t"]
    hub_clear = P["drive_hub_clear"]
    for sgn in (-1, 1):
        cuts.append(L.cyl(P["drive_bearing_od"] / 2.0, bw,
                          min(sgn * X_WALL, sgn * (X_WALL - bw)),
                          Y_REAR, AXLE, axis="x"))
        cuts.append(L.cyl(hub_clear / 2.0, boss_t + WALL + 2,
                          min(sgn * (X_WALL_IN - boss_t), sgn * X_WALL) - 1,
                          Y_REAR, AXLE, axis="x"))
    return cuts


# --- motor retention cap (separate print, x2) ----------------------------
def motor_cap():
    """Closes the cradle slot and holds a motor in. One part, printed twice.

    Built about the origin with the motor axis along X rather than in place, so
    it exports as a printable part (same convention as the caster pieces). The
    tongue drops into the cradle slot and is carved out by the motor body,
    leaving a saddle that bears on the top of the can. The plate is held
    motor_cap_clamp_gap above the cradle top so the four M2 screws preload the
    motor down into the bore instead of bottoming the plate out first.
    """
    fit = P["motor_cap_fit"]
    cradle_l, cradle_w, cradle_top = _cradle_dims()
    cap_l, cap_w = _cap_dims()
    # cradle top and plate underside, expressed relative to the motor axis
    top_rel = cradle_top - AXLE
    plate_z = top_rel + P["motor_cap_clamp_gap"]

    plate = L.box(cap_l, cap_w, P["motor_cap_t"], 0, 0, plate_z)
    # Tongue is sized off the cap plate, not the cradle, so it can never end up
    # longer than the plate carrying it.
    tongue = L.box(cap_l - 2 * fit,
                   P["motor_dia"] + P["motor_fit_clear"] - 2 * fit,
                   plate_z, 0, 0, 0.0)
    solid = plate.fuse(tongue)
    # carve the saddle: nominal motor radius, no clearance, so the cap grips
    solid = solid.cut(L.cyl(P["motor_dia"] / 2.0, cradle_l + 4,
                            -(cradle_l + 2) / 2.0, 0, 0, axis="x"))
    # M2 clearance holes over the cradle's tapped columns
    for dx in (-P["motor_cap_screw_x"] / 2.0, P["motor_cap_screw_x"] / 2.0):
        for dy in (-P["motor_cap_screw_cc"] / 2.0, P["motor_cap_screw_cc"] / 2.0):
            solid = solid.cut(L.cyl(P["m2_tap_dia"] / 2.0 + 0.3, P["motor_cap_t"] + 2,
                                    dx, dy, plate_z - 1))
    return solid


# --- idler tensioning slot -----------------------------------------------
def idler_features():
    """Fore-aft slot and carrier bosses for the tensioned idler rod.

    The rod no longer sits in a fixed hole. The printed track loop closes at a
    119.38 mm straight run -- 29 lugs at the sprocket's own 12.566 mm tooth
    pitch -- which is 0.62 mm shorter than the nominal 120 mm wheelbase, so even
    at zero strain the rod does not belong at Y_FRONT. It runs in a slot, is
    located by a carrier inside the tub, and pretension is whatever the carrier
    gets clamped at: 1 mm forward is 2 mm of path, 0.55 % strain in the TPU.

    The old inner-face pads are gone with the fixed hole. Their job was shaft
    bearing length, which the carrier now provides; left in place they would
    only hold the carrier off the wall.

    The carrier bears on two bosses rather than on the wall itself, because the
    wall is 2.4 mm and an M2 thread needs more than that. The boss end faces are
    what the carrier slides across, and they stay clear of its slot travel by
    being centred on the fixed tapped holes.
    """
    solids, cuts = [], []
    r = P["axle_hole_dia"] / 2.0
    ln = P["idler_slot_len"]
    bt = P["idler_boss_t"]
    depth = bt + WALL - 0.4                       # blind: never breaks the outer face
    for sgn in (-1, 1):
        x0 = min(sgn * X_WALL, sgn * X_WALL_IN) - 1.0
        cuts.append(L.box(WALL + 2, ln - 2 * r, 2 * r,
                          x0 + (WALL + 2) / 2.0, Y_IDLER, AXLE - r))
        for e in (-1, 1):
            cuts.append(L.cyl(r, WALL + 2, x0,
                              Y_IDLER + e * (ln / 2.0 - r), AXLE, axis="x"))
        for i in range(2):
            z = AXLE + P["idler_carrier_screw_z0"] + i * P["idler_carrier_screw_cc"]
            bx = min(sgn * X_WALL_IN, sgn * (X_WALL_IN - bt))
            solids.append(L.cyl(P["boss_od"] / 2.0, bt, bx, Y_IDLER, z, axis="x"))
            cuts.append(L.cyl(P["m2_tap_dia"] / 2.0, depth, bx, Y_IDLER, z, axis="x"))
    return solids, cuts


# --- road-wheel axle skirts ----------------------------------------------
def roadwheel_axles():
    """Skirt pads below each side wall, carrying the two road-wheel rods.

    A ø24 road wheel reaches the track's inner surface only from an axle line at
    15.5 mm, and the tub floor's underside is at 18 -- so the holes the wall used
    to carry at 23.5 were 8 mm too high for the wheel to touch anything, and the
    obvious fix of lowering them lands 2.5 mm below the bottom of the wall.
    Each rod therefore gets a local pad hanging off the wall, thickened inboard
    so the rod bears on 5.4 mm of material rather than 2.4.

    Separate pads per rod rather than one long skirt: 2 g lighter, and the pad
    has no structural job between the rods.
    """
    solids, cuts = [], []
    r = P["axle_hole_dia"] / 2.0
    thick = WALL + P["skirt_pad_t"]
    z0 = P["skirt_z_bottom"]
    h = (Z0 + 1.0) - z0                            # 1 mm up into the wall/floor
    for y in j5_params.roadwheel_ys(P):
        for sgn in (-1, 1):
            solids.append(L.box(thick, P["skirt_len"], h,
                                sgn * (X_WALL - thick / 2.0), y, z0))
            cuts.append(_wall_hole(sgn, y, RW_AXLE, r, thick))
    return solids, cuts


# --- battery bay ---------------------------------------------------------
def battery_bay():
    """Three-sided bay ring: side walls plus a forward end stop, open aft.

    The ring used to run the full length of the pack, which put 12 mm of wall
    right across the motor cradle's inboard opening -- blocking hand access and
    the motor's rear wire exit. It now stops battery_bay_aft_clear short of the
    cradle face.

    That makes the ring shorter than the pack, so it cannot have an aft end
    wall: one at bay_aft_y would sit 14.5 mm inside the pack's footprint and
    stop it seating. The pack's aft end is therefore unfenced and held by the
    straps; if it walks in testing, a drop-in aft stop fitted after the motors
    are in is the fix, rather than putting the wall back.
    """
    bw = P["battery_w"] + 2 * P["battery_clear"]   # along X
    wall = 2.0
    floor = Z0 + WALL
    ring_h = P["battery_h"] * 0.6
    y_aft, y_fwd = P["bay_aft_y"], P["bay_fwd_y"]
    ring_l = y_fwd - y_aft

    outer = L.box(bw + 2 * wall, ring_l, ring_h, 0, (y_aft + y_fwd) / 2.0, floor)
    # Inner cut runs past the aft face, so no end wall is left there.
    inner = L.box(bw, ring_l - wall + 1, ring_h + 1, 0,
                  (y_aft - 1 + y_fwd - wall) / 2.0, floor)
    ring = outer.cut(inner)
    # strap slots through the long walls, moved inboard with the ring
    cuts = [L.box(bw + 2 * wall + 2, 6, ring_h - 3, 0, y_aft + 5, floor + 2),
            L.box(bw + 2 * wall + 2, 6, ring_h - 3, 0, y_fwd - wall - 5, floor + 2)]
    return ring, cuts


# --- Pi-M electronics shelf: support columns on the tub -------------------
def _shelf_screw_xy():
    """Shelf screw centres, shared by the tub's tapped columns and the plate's
    clearance holes so the two cannot land in different places."""
    return [(sx * P["pi_rib_cx"], y)
            for sx in (-1, 1) for y in j5_params.pi_column_ys(P)]


def pi_shelf_columns():
    """Columns carrying the electronics shelf. Returns (solid, cuts).

    Was two solid 8.4 x 73 mm ribs. The shelf now runs 62 mm further aft so it
    can carry the IMU breadboard as well as the Pi, and ribs at that length
    would have been 58 g of wall; three columns a side do the same job for 23 g,
    and the gaps between them are where wiring crosses underneath.

    Columns also delete the idler-rod notch. The rod crosses this band at axle
    height, and the old rib had a hole cut through it to let the rod pass;
    pi_column_ys instead places the forward column clear of the rod's travel, so
    there is nothing to notch and nothing to mis-align on assembly. It clamps
    the aft column off the motor cradles for the same reason: the plate reaches
    back over them now, and a column at its aft edge would stand in the motor
    drop-in pocket.
    """
    z = Z0 + WALL + P["pi_shelf_z"]
    depth = P["motor_cap_screw_depth"]
    solid, cuts = None, []
    for sx, sy in _shelf_screw_xy():
        col = L.box(P["pi_rib_t"], P["pi_column_len"], z - (Z0 + WALL),
                    sx, sy, Z0 + WALL)
        solid = col if solid is None else solid.fuse(col)
        cuts.append(L.cyl(P["m2_tap_dia"] / 2.0, depth + 1, sx, sy, z - depth))
    return solid, cuts
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

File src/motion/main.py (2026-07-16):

"""Motion loop entry point for Pi-M.

Phase 01 built the loop skeleton and the offline fallback state machine.
Phase 02 Task 2 activates the locomotion seam that Tasks 1/3-5 left staged:
MotorDriver (Task 1, H-bridge + encoders) and LocomotionPolicy (Task 5, ONNX
runner) are wired into execute_intent(); _read_motion_state() builds the
policy's MotionState from the MPU-6050 (this task) fused with EncoderReader
odometry. Manipulation dispatch (arm_pose / head_pose) is added in Phase 03.
"""

from __future__ import annotations

import logging
import os
import time
from dataclasses import dataclass

from motion.locomotion_policy import LocomotionPolicy, MotionState, command_from_intent
from motion.motor_driver import EncoderReader, MotorDriver
from motion.mpu6050 import MPU6050
from motion.offline_fallback import OfflineFallbackStateMachine, State

logging.basicConfig(level=logging.INFO)
logger = logging.getLogger("johnny5.motion.main")

LOOP_RATE_HZ = 50  # 20ms tick -- profile sustainability on Pi Zero 2 W in Phase 02

_HERE = os.path.dirname(os.path.abspath(__file__))
_REPO = os.path.normpath(os.path.join(_HERE, "..", ".."))
POLICY_PATH = os.path.join(_REPO, "policies", "locomotion_v3.onnx")

# Sprocket pitch radius + track thickness (mechanical/freecad/params.csv:
# sprocket_pitch_dia=40mm / 2 + track_thickness=3.5mm). Same CSV source as
# simulation/chassis/params.py's wheel_radius -- if that geometry changes,
# update this alongside it (and re-check the V_MAX/W_MAX-vs-wheel-speed
# relationship the policy was trained against).
WHEEL_RADIUS_M = 0.0235

# Locomotion actions execute_intent() dispatches through the policy. "idle" is
# intentionally excluded here (matches the seam as documented/staged in Task
# 5) -- it is a valid command_from_intent() input (-> hold-still (0,0)) for
# testing/future use, but execute_intent() currently only drives the motors on
# an explicit move/turn/arc; an idle intent is a no-op for locomotion this tick.
_LOCOMOTION_ACTIONS = ("move", "turn", "arc")


@dataclass
class MotionHardware:
    """Task 1/2 hardware handles, built once by initialize_hardware().

    Held as an injectable bundle (not bare module globals) so execute_intent(),
    _read_motion_state(), and _apply_fallback_output() are unit-testable with
    fakes in the sandbox -- see tests/test_main_locomotion.py. Real hardware
    construction (gpiozero, rpi-hardware-pwm, smbus2, onnxruntime) happens
    lazily inside each component's own __init__, only when
    initialize_hardware() actually runs -- this module imports cleanly
    off-target.
    """

    motor_driver: "MotorDriver | None" = None
    policy: "LocomotionPolicy | None" = None
    imu: "MPU6050 | None" = None
    encoders: "EncoderReader | None" = None


_hw = MotionHardware()


def initialize_hardware(hw: MotionHardware | None = None) -> MotionHardware:
    """Construct MotorDriver, LocomotionPolicy, MPU6050, EncoderReader.

    MotorDriver is constructed disabled (STBY low -- its own fail-safe
    default); main()'s loop enables/disables it each tick from the offline
    fallback state via _apply_fallback_output(), it is never force-enabled
    here. Pass an explicit `hw` (pre-built with fakes) to bypass real hardware
    construction -- used by tests, not by main().
    """
    global _hw
    hw = hw or MotionHardware(
        motor_driver=MotorDriver(),
        policy=LocomotionPolicy(POLICY_PATH),
        imu=MPU6050(),
        encoders=EncoderReader(),
    )
    _hw = hw
    logger.info(
        "initialize_hardware: MotorDriver + LocomotionPolicy + MPU6050 + "
        "EncoderReader ready (disabled until ONLINE)"
    )
    return hw


def initialize_mqtt():
    """Stub. Returns an MQTT client handle once implemented."""
    logger.info("initialize_mqtt: stub (no-op in Phase 01/02)")
    return None


def get_latest_intent(mqtt_client, state_machine: OfflineFallbackStateMachine):
    """Stub. Reads latest retained johnny5/intent message, if any.
    Must not block waiting for a new message -- returns None if nothing new.
    """
    return None


def _read_motion_state(hw: MotionHardware | None = None) -> MotionState:
    """Build a MotionState from live sensors for this tick.

    Sensor -> channel map (simulation/chassis/TUNING.md "Observation
    reconstruction on Pi-M"):
      roll, pitch, yaw_rate   <- MPU-6050 accel+gyro complementary filter (motion.mpu6050)
      wheel_speed_left/right  <- EncoderReader.read(), rad/s
      forward_velocity        <- mean drive-wheel speed * WHEEL_RADIUS_M (encoder odometry)
      lateral_velocity        <- not directly measurable, held at 0.0 (documented sim-to-real gap)
    """
    hw = hw or _hw
    roll, pitch, yaw_rate = hw.imu.read()
    enc = hw.encoders.read()
    forward_velocity = 0.5 * (enc.speed_left + enc.speed_right) * WHEEL_RADIUS_M
    return MotionState(
        roll=roll,
        pitch=pitch,
        yaw_rate=yaw_rate,
        forward_velocity=forward_velocity,
        lateral_velocity=0.0,
        wheel_speed_left=enc.speed_left,
        wheel_speed_right=enc.speed_right,
    )


def execute_intent(intent, hw: MotionHardware | None = None) -> None:
    """Dispatch an intent to actuation via the trained locomotion policy.

    intent -> command_from_intent -> LocomotionPolicy.step(state, cmd) ->
    MotorDriver.set_speed. hw defaults to the module-level handles built by
    initialize_hardware(); pass an explicit MotionHardware (with fakes) to
    unit-test this without a Pi.

    Manipulation (arm_pose / head_pose) is dispatched from here in Phase 03.
    """
    hw = hw or _hw
    if intent is None:
        return
    action = intent.get("action")
    if action not in _LOCOMOTION_ACTIONS:
        logger.debug("execute_intent: no locomotion action in intent=%s", intent)
        return
    if hw.motor_driver is None or hw.policy is None or hw.imu is None or hw.encoders is None:
        logger.warning("execute_intent: hardware not initialized, dropping intent")
        return
    v_cmd, w_cmd = command_from_intent(action, intent.get("params"))
    state = _read_motion_state(hw)
    left, right = hw.policy.step(state, (v_cmd, w_cmd))
    hw.motor_driver.set_speed(left, right)
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

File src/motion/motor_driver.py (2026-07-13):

"""Motor driver + encoder reader for Pi-M (Phase 02, Task 1).

Drives the two tread motors through a TB6612FNG dual H-bridge (BOM section 1) and
reads the N20 quadrature encoders. Speed (PWMA/PWMB, GPIO 12/13) uses the Pi's
kernel hardware-PWM peripheral via `rpi-hardware-pwm` (requires
`dtoverlay=pwm-2chan` in /boot/firmware/config.txt); the direction and STBY lines
and the encoders use gpiozero on the lgpio pin factory. Hardware-timed PWM keeps
the 20 kHz carrier glitch-free and off the CPU -- which matters inside the 50 Hz
motion loop on the single-core Pi Zero 2 W (lgpio's own PWM is software-timed).

TB6612FNG control contract (docs/HARDWARE_drive_bringup.md), per channel, STBY HIGH:

    IN1 IN2 PWM   result
    H   L   duty  forward (speed proportional to duty)
    L   H   duty  reverse
    H   H    x    short brake (terminals shorted)
    L   L    x    coast (outputs high-Z)

With a direction set, PWM=0 is a short brake, NOT a coast -- true coast is
IN1=L, IN2=L. STBY LOW forces all outputs off and is the boot/crash/offline
fail-safe. STBY is held LOW at construction; nothing drives until enable().

Hardware access sits behind a small backend so the control logic is unit-testable
without a Pi (see tests/test_motor_driver.py). The real backend imports gpiozero
and rpi-hardware-pwm lazily, so this module imports cleanly off-target.
"""

from __future__ import annotations

import logging
import math
import time
from dataclasses import dataclass
from typing import Protocol

logger = logging.getLogger("johnny5.motion.motor_driver")

# --- Pin map (Pi-M, BCM) -- BOM.md GPIO map + docs/HARDWARE_drive_bringup.md ---
PWM_FREQ_HZ = 20_000          # above audible, well under the TB6612 100 kHz max
PWM_CHIP = 0                  # Pi Zero 2 W (BCM2837): pwmchip0. (Pi 5 would be 2.)


@dataclass(frozen=True)
class MotorPins:
    pwm_channel: int          # kernel PWM channel: 0 -> GPIO12 (A), 1 -> GPIO13 (B)
    in1: int                  # direction pin (BCM)
    in2: int                  # direction pin (BCM)


LEFT_PINS = MotorPins(pwm_channel=0, in1=5, in2=6)      # motor A: PWMA/AIN1/AIN2
RIGHT_PINS = MotorPins(pwm_channel=1, in1=16, in2=26)   # motor B: PWMB/BIN1/BIN2
STBY_PIN = 20

ENC_LEFT_A, ENC_LEFT_B = 17, 27
ENC_RIGHT_A, ENC_RIGHT_B = 22, 23
# gpiozero.RotaryEncoder decodes full-step (one count per full quadrature cycle,
# i.e. 1x), so effective resolution is 3 cycles/motor-rev x 150.58 gearbox
# ~= 452 counts/output-rev -- NOT the raw 4x figure (12 CPR x 150.58 ~= 1807).
# Bench data (Task 1) showed counts running ~4x below the 1807 assumption.
# Provisional; confirm/refine with `scripts/test_motors.py --calibrate`.
COUNTS_PER_OUTPUT_REV = 451.74


# --------------------------------------------------------------------------- #
# Hardware backend abstraction (swappable for tests)                          #
# --------------------------------------------------------------------------- #
class DigitalOut(Protocol):
    def set(self, high: bool) -> None: ...
    def close(self) -> None: ...


class PwmOut(Protocol):
    def duty(self, percent: float) -> None: ...   # clamp + apply 0..100 % duty
    def close(self) -> None: ...


class GpioBackend(Protocol):
    def digital_out(self, bcm: int, initial_high: bool = False) -> DigitalOut: ...
    def pwm_out(self, channel: int, freq_hz: int) -> PwmOut: ...


class _GzDigitalOut:
    def __init__(self, dev) -> None:
        self._dev = dev

    def set(self, high: bool) -> None:
        self._dev.on() if high else self._dev.off()

    def close(self) -> None:
        self._dev.close()


class _HwPwmOut:
    def __init__(self, pwm) -> None:
        self._pwm = pwm

    def duty(self, percent: float) -> None:
        self._pwm.change_duty_cycle(max(0.0, min(100.0, float(percent))))

    def close(self) -> None:
        try:
            self._pwm.stop()
        except Exception:  # pragma: no cover - best-effort teardown
            pass


class RealGpioBackend:
    """gpiozero (lgpio) direction/STBY lines + rpi-hardware-pwm speed channels."""

    def __init__(self, pwm_chip: int = PWM_CHIP) -> None:
        self._pwm_chip = pwm_chip
        # Pin the lgpio factory explicitly. gpiozero 2.x defaults to it on
        # Trixie/Bookworm, but being explicit stops a silent fall-back to a
        # degraded factory (e.g. RPi.GPIO, which is broken on these kernels).
        try:
            from gpiozero import Device
            from gpiozero.pins.lgpio import LGPIOFactory
            if not isinstance(Device.pin_factory, LGPIOFactory):
                Device.pin_factory = LGPIOFactory()
        except Exception:  # pragma: no cover - host dependent
            logger.warning("lgpio pin factory unavailable; using gpiozero default")

    def digital_out(self, bcm: int, initial_high: bool = False) -> DigitalOut:
        from gpiozero import DigitalOutputDevice
        return _GzDigitalOut(DigitalOutputDevice(bcm, initial_value=initial_high))

    def pwm_out(self, channel: int, freq_hz: int) -> PwmOut:
        from rpi_hardware_pwm import HardwarePWM
        pwm = HardwarePWM(pwm_channel=channel, hz=freq_hz, chip=self._pwm_chip)
        pwm.start(0.0)
        return _HwPwmOut(pwm)
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

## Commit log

2026-06-17 hw: add Phase 00 BOM, pin maps, and power budget
2026-06-17 hw: update BOM status to approved and document session handoff details
2026-06-17 hw: update tread and filament specifications for improved performance
2026-06-19 hw: add FreeCAD parametric models, massing previews, and reference images
    [components.csv, params.csv]
2026-06-20 Add Phase 06 documentation for Form & Finish process
    - Introduced a new phase focused on refining the cosmetic geometry of the Johnny 5 robot.
    - Defined objectives, gate conditions, context, tasks, dependencies, and open questions for the phase.
    - Emphasized the importance of achieving a cohesive and screen-accurate form while adhering to weight constraints.
    [antenna_v1.stl, arm_assembly_v1.FCStd, arm_left_v1.stl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]
2026-06-22 feat: add chassis simulation environment
2026-06-27 feat: update INITIATING_PROMPT with Phase 02 progress and add HARDWARE_drive_bringup documentation for MotorDriver integration
2026-06-27 feat: implement motor driver and encoder reader for Phase 02 locomotion stack; add test suite for TB6612FNG control
2026-06-28 Add complete wiring schematic for Johnny 5 Drive Bench and update Step 2 diagram
    - Introduced a new SVG diagram for the complete wiring schematic of the Johnny 5 Drive Bench, detailing connections for the Raspberry Pi, TB6612FNG motor driver, and bench supply.
    - Updated the Step 2 diagram to clarify the ground and 3.3 V logic rail connections, including detailed notes on wiring and component specifications.
2026-07-13 feat: add encoder calibration functionality and update counts/output-rev based on bench results
2026-07-16 feat: wire locomotion policy into motion loop
2026-07-16 feat: split physical integration test into encoder calibration and floor integration; update documentation for task requirements
2026-08-10 feat: add dwell parameter to motor test script for extended phase observation
2026-08-10 feat: update encoder calibration process to operate under power and improve accuracy
2026-08-10 feat: update phase documentation and tuning log with encoder calibration results and method changes
2026-08-10 feat: implement motor retention cap design and update cradle geometry for secure motor mounting
    [params.csv]
2026-08-11 fix: remove stale git lock and commit pending changes
    [chassis_assembly_v1.FCStd, chassis_deck_v1.stl, chassis_tub_v1.stl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]
2026-08-13 Add initial version of motor cap STL file
2026-08-13 fix: correct side-wall hole handedness, motor insertion and internal keep-outs
    [params.csv]
2026-08-20 Reopen Phase 00 for chassis rework; document Session 03 decisions and open threads for drivetrain development. Update hardware specifications and FreeCAD MCP integration details.
    [chassis_assembly_v1.FCStd, chassis_tub_v1.stl, motor_cap_v1.stl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]
2026-08-22 hw: close Phase 00 -- drivetrain, chassis rework, 2.0 mm shells, 1531 g
    [axle_collar_v1.stl, caster_arm_v1.stl, caster_wheel_v1.stl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]
2026-08-23 chore: track deployed locomotion policy
2026-08-25 docs: power wiring and harness schematic, closing B5 and O6
    Formal power and harness definition for the whole robot: hand-authored SVG on the bench_full_schematic.svg convention, a 64-net companion document with a per-rail reconciliation and a build order, and scripts/check_harness_nets.py, which asserts GPIO existence and uniqueness against both BOM pin maps, rail totals against the Power Budget and the section 6 ratings, endpoint parts against BOM line items, passive values against BOM line items, and net-name parity between the drawing and the document.
    O6 resolved against the Pololu catalogue: both drive motors are #5218 at .45 each. BOM section 1 corrected from to for the pair; a res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
    [check_harness_nets.py]
2026-08-25 docs: record Andrew's rulings on the motor variant, cables and fuse
    Section 9 addendum to the J5-S17 report. The #5218/#5219 split was a deliberate fit test: the side-connector #5219 does not fit the chassis, both drive motors are #5218, and #5218 is the only drive motor this project will use. The 6-pin JST SH encoder cables ship with the motors and need no BOM line; the sentence added earlier today saying otherwise is corrected. The fuse margin was informational, not a decision: the 7.5 A blade stands, with two standing cautions retained.
    The three remaining #5219 references in docs/HARDWARE_drive_bringup.md, docs/diagrams/bench_full_schematic.svg and simulation/chassis/TUNING.md are now p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
2026-08-25 docs: record the PowerShell line-ending check, tr and wc are unavailable
2026-08-26 docs: remove the five root project-memory notes and their index
    Agent scratch exported from a project-memory store, and a second state store with its own index inside a repository whose central lesson is that this is how it fails. johnny5-pi-m-env.md was salvaged first, in the preceding commit. The other four are fully covered by CLAUDE.md, docs/ORCHESTRATION.md sections 6 and 7, PROJECT_STATE.md section 9 and simulation/chassis/README.md; the coverage is tabulated in docs/reports/J5-S19.md section 3(e). johnny5-phase02-locomotion.MD also carried the last stale #5218/#5219 reference, which closes O18. johnny5-cloud-mount-quirks.MD asserted a git permission the project withdrew on 2026-08-23.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
2026-08-26 docs: clarify the 1807 encoder figure, simplify the bench wiring key, ignore .claude/
    docs/HARDWARE_drive_bringup.md carried the raw 4x quadrature count at lines 16 and 73 with nothing beside it naming COUNTS_PER_OUTPUT_REV; line 73 sat next to gpiozero.RotaryEncoder, the 1x decoder that makes it wrong. Both now carry the clarification BOM.md received at O14 and point at simulation/chassis/TUNING.md; neither figure is deleted, since 1807 is correct as the raw figure. The bench schematic's wiring key prefixed all six rows #5218 when the column headers already distinguish the motors and there is no left/right variant; the rows now read LEFT and RIGHT and the three real part labels are untouche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
2026-08-27 hw: carry the IMU on a breadboard aft on the Pi-M shelf
    [chassis_assembly_v1.FCStd, chassis_tub_v1.stl, components.csv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]
2026-08-27 hw: print the track loop as a circle rather than in its running shape
    [components.csv, drivetrain_v1.FCStd, track_loop_v1.stl]
2026-08-27 docs: add the Pi-V runtime document
    Pi-M has had a runtime document since S19; Pi-V had none, and O1 already names docs/HARDWARE_pi_v_runtime.md as where the combined simple-audio-card overlay belongs when it is written. This is that file. It records the box (johnny5-vision, 192.168.1.218, Trixie 64-bit, administrator, ~/johnny5-env), the camera enablement step Phase 01 specifies, src/vision/requirements-vision.txt as the dependency declaration, and the .env configuration with the 60 s LiteLLM timeout and why it differs from the in-code default. Two gaps are stated rather than solved: the O1 audio overlay, which stays Phase 04 work because it cannot be tested from a session, and the absence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
2026-08-27 docs: verify J5-S22 close-out, log Andrew's CAD commits, open O22-O27
    S22 verified against the repository with nothing failing and no factual error found in it. D8 closed: docs/HARDWARE_pi_v_runtime.md is on main as 248a41d. S22's precondition judgement call upheld and the lesson assigned to the brief rather than the worker. 23157ef and ecb244f logged in a new section 4 table for commits from no dispatched session, with both design decisions recorded in section 9; the Phase 00 mass figure re-derived at 1542 g and the gate confirmed to hold. O22 opened: a live LiteLLM key has been in .env.example since 22ad422 and the GitHub remote is public, confirmed this turn. O23, O24, O25, O26 and O27 op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
2026-08-27 docs: re-quote the mass budget from the script that prints it
    Lines 173 and 181 both stated 1531 g against the 1.6 kg ceiling. mechanical/preview/mass_budget.py prints 1542 g, 96.4 % of ceiling, 58 g headroom and 1597 g at +25 %, and both lines now say so with the script named as the source. The 11 g came from 23157ef alone; ecb244f touched components.csv the same evening but moved no mass. O23 states both commits as the cause and is wrong on the second.
2026-08-27 docs: verify J5-S23 close-out, correct the O23 mass attribution, empty the queue
    S23 verified against the repository with nothing failing. O23 and section 3 both attributed the 11 g mass move to 23157ef and ecb244f; mass_budget.py run at 23157ef^, 23157ef and ecb244f gives 1531/1542/1542, so the whole 11 g is 23157ef and ecb244f moved none. Both corrected. O27 requalified as fixed-in-the-working-tree, D9 closed, O5 scoped. O28 opened: a FreeCAD GUI open-and-close modifies a megabyte-scale .FCStd with no engineering content, proven by unzipping the uncommitted drivetrain_v1.FCStd and finding all twelve geometry members byte-identical to HEAD. No worker session dispatched: the queue holds noth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
2026-08-28 docs: reconcile S23's landing, close O23 and O27, archive pass, queue D10
